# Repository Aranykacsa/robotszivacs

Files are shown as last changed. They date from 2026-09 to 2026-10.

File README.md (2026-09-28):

# Vacuum whiteboard robot — assembly prototype

The revised model uses **four drive motors**, a full-bottom sponge with an actual vacuum aperture, a gasketed adapter for a **QX-Motor 30 mm six-blade EDF / QF1611**, supported mechanical assemblies and a removable sports-car-style cover. Four TCRT5000 cartridges attach to the chassis ahead of/behind the wheels; they do not mount on the wheels.

The Blender Outliner groups parts under **Robot Components** into Chassis, Vacuum System, Drivetrain, Rear Wiper, Top Electronics, Board Sensors, Charging Contacts, Sports Car Body, Other Components and Collision Helpers. Toggle a collection's eye icon to hide/show that logical group; the individual meshes remain separate and parented to Chassis.

The hardware PDF supplies the component families. The user subsequently confirmed four motors, adhesion-only vacuum, no fixed footprint limit and a preference for printed construction. The selected EDF's duct ID/length and its mounting drawing are not supplied by the vendor, so the model's 25.5 mm bore and clamp fit are explicitly provisional. The model selects 14,000 KV for the 2S setup; check the marking on the actual motor. The vendor's 19.3 A 2S full-throttle point exceeds a 500 mAh 30C pack's nominal 15 A continuous rating.

## Open the result

- `Vacuum_Robot_Blockout.blend` — revised assembled model, component properties and studio setup.
- `robot_assembled.png`, `robot_underbody.png`, `robot_service.png` — assembled, underside and cover-off views.
- `robot_build_state.md` — flushed step-by-step component log, absolute dimensions/positions, build checks and completion status.
- `manufacturing/` — individual prototype STLs in mm, full-pad cutting template and validation report.
- `godot_vacuum_robot/project.godot` — playable whiteboard-cleaning demo built around the unchanged true-scale robot GLB.
- [Assembly and manufacturing notes](design/ASSEMBLY.md).
- [TCRT5000 mounting details and references](design/SENSOR_MOUNT.md).

The original blockout is preserved in `archive/blockout_v1/`. The original `robotszivacs.blend` is untouched.

## Generate everything

```bash
blender --background --python-exit-code 1 --python build_vacuum_robot.py -- --godot-bin /absolute/path/to/godot
```

For this machine's Flatpak Blender installation and downloaded validation binary:

```bash
flatpak run org.blender.Blender --background --python-exit-code 1 \
  --python "$PWD/build_vacuum_robot.py" -- \
  --godot-bin /home/aranykacsa/.cache/vacuum_robot_tools/godot
```

Optional arguments: `--output-dir DIR`, `--skip-render`, `--skip-godot`. Without an explicit Godot path, the script checks `GODOT_BIN`, then `godot4` and `godot` on PATH. Missing Godot is logged; an execution failure raises an exception. Rendering uses Cycles on the available device.

The script clears the current scene and replaces generated output. In Blender's Text Editor it writes beside the current `.blend`; in a fresh background session it writes beside the script. One Blender unit is one meter. STL export explicitly converts back to mm. X is right, Y is front, Z is away from the board; the board is Z=0 and the chassis base starts at Z=2 mm.

## What is checked

The script checks that every printed part is a connected manifold solid, that all robot meshes are directly parented to the one chassis object, and that object scale is applied. It checks four common shaft/hub axes, wheel and roller board contact, an open central passage and off-axis ray through EDF blade gaps, the sensors' unobstructed downward sightlines and nominal 2.5 mm optical-face height, and cover surface interference with the principal purchased-part envelopes. It exports Godot and runs headless import/runtime checks when Godot is available.

These checks do not establish actual component fit, pressure/flow performance, adhesion or production readiness. The print files are **fit prototypes**. Follow the assembly notes before fabricating final parts.

## Godot and physics metadata

The Godot project opens directly into a maximized, classroom-scale demo with Lorem Ipsum wrapped across fifteen whiteboard rows, leaving a marked lower-right docking bay. **W/S** throttle, **A/D** steer, **Home** performs a corner-parking approach and aligns the front pogo pins with two copper dock pads, and **R** resets the scene. The pad centers match the model's 32 mm pogo spacing and 104.1 mm pin reach; charging begins only when both simulated pin tips contact their pads. The robot erases text under its sponge footprint, shows cleaning progress and a one-minute battery countdown, charges while docked, and falls to the classroom floor when empty. **F11** toggles fullscreen. The robot model itself is unchanged.

Each robot mesh has `Weight` in grams, `Voltage` in volts and `Part Type`. Unknown masses/ratings are `-1`; properties distinguish generic envelopes, rated motor voltage and estimated mass. Drive motors are rated **6 V**, while the battery is **7.4 V nominal**. Do not infer electrical compatibility from the visual layout.

Helpers use `-colonly` for apertured structures and `-convcolonly` for simple envelopes. Godot removes helper visuals during import. The demo is static. Replace concave static geometry with suitable convex shapes under one `RigidBody3D` before attempting dynamic simulation; establish the finished assembly mass separately.

## References

- Local `Automata Vákuumos Táblatörlő Robot – Hardverspecifikáció.pdf`.
- [Research and downloaded complete CAD models](references/RESEARCH_AND_REDESIGN.md).
- [Vishay TCRT5000 datasheet](https://www.vishay.com/docs/83760/tcrt5000.pdf).
- [Blender glTF export API](https://docs.blender.org/api/current/bpy.ops.export_scene.html).
- [Godot import naming conventions](https://docs.godotengine.org/en/stable/tutorials/assets_pipeline/importing_3d_scenes/node_type_customization.html).

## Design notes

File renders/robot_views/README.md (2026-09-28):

# Vacuum robot render set

Fourteen PNG views rendered from `Vacuum_Robot_Blockout.blend`. The render pass changes only temporary in-memory visibility and transforms; it does not save or alter the Blender model.

## 01 Assembled Hero Hood Down

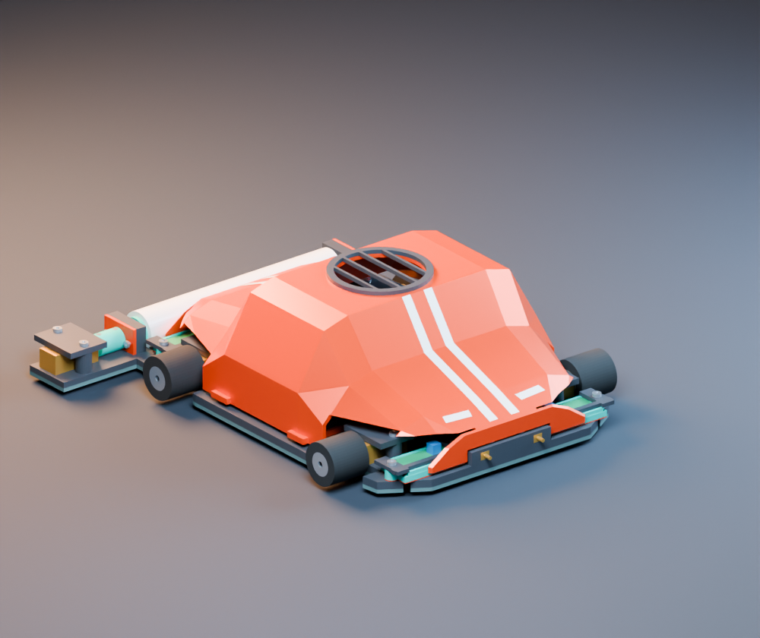
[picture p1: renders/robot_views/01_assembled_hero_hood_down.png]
01 Assembled Hero Hood Down


## 02 Front Three Quarter Hood Down

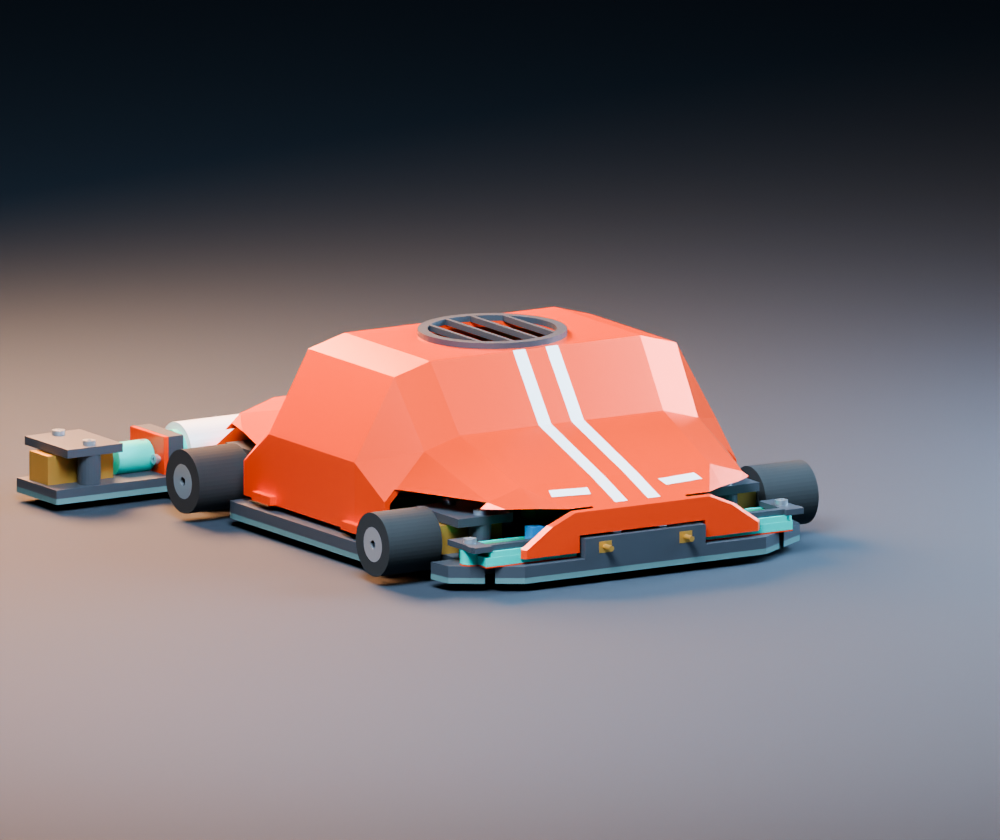
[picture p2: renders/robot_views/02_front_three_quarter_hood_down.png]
02 Front Three Quarter Hood Down


## 03 Side Profile Hood Down

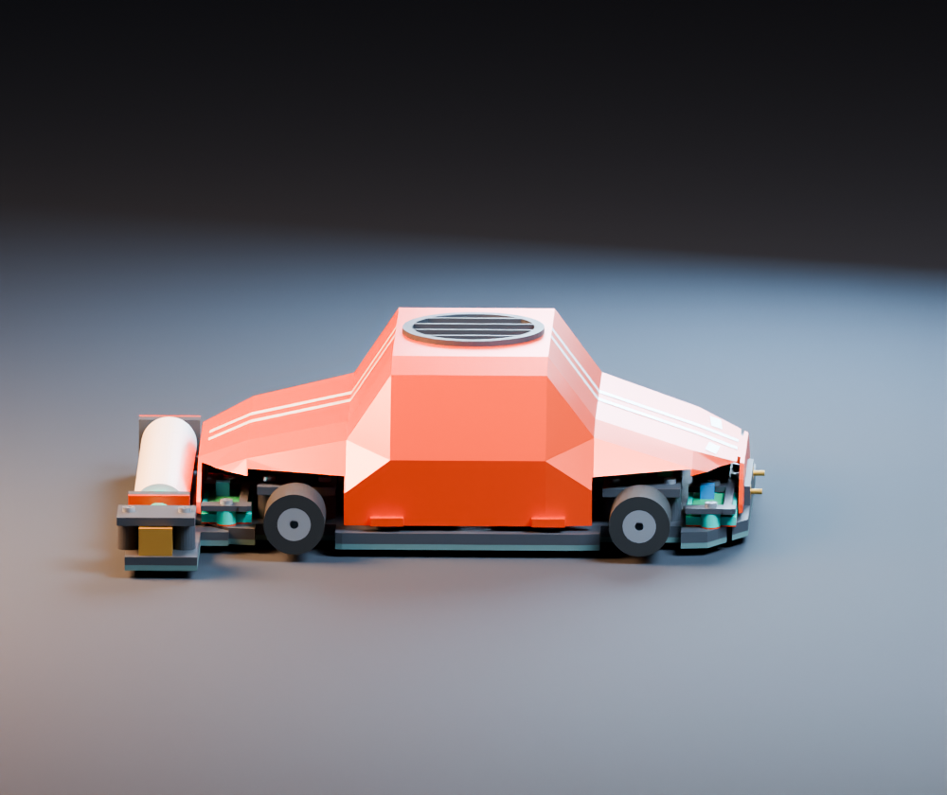
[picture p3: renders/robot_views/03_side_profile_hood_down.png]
03 Side Profile Hood Down


## 04 Rear Three Quarter Hood Down

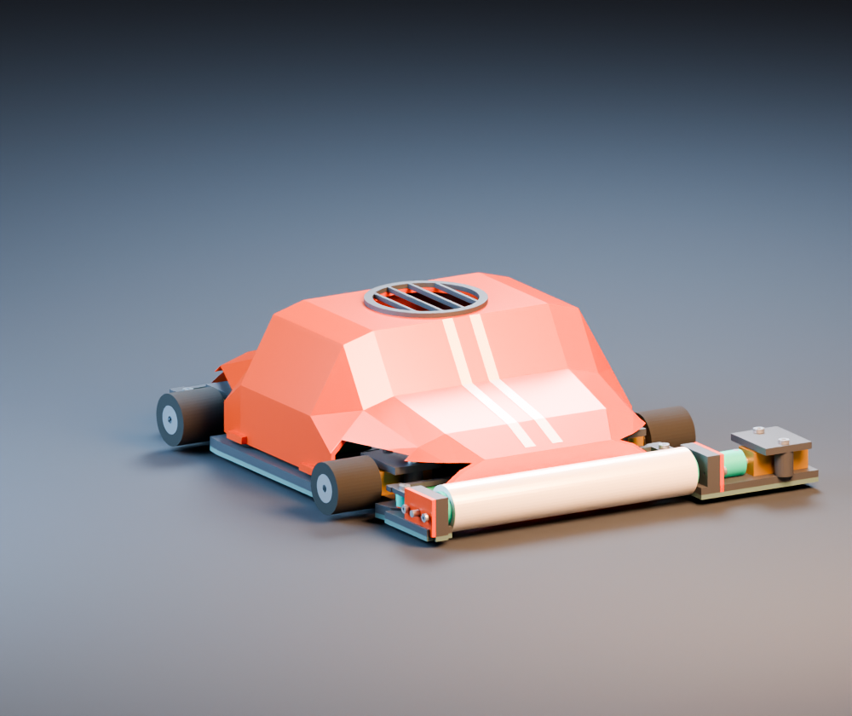
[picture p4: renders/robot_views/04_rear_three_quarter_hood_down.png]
04 Rear Three Quarter Hood Down


## 05 Top View Hood Down

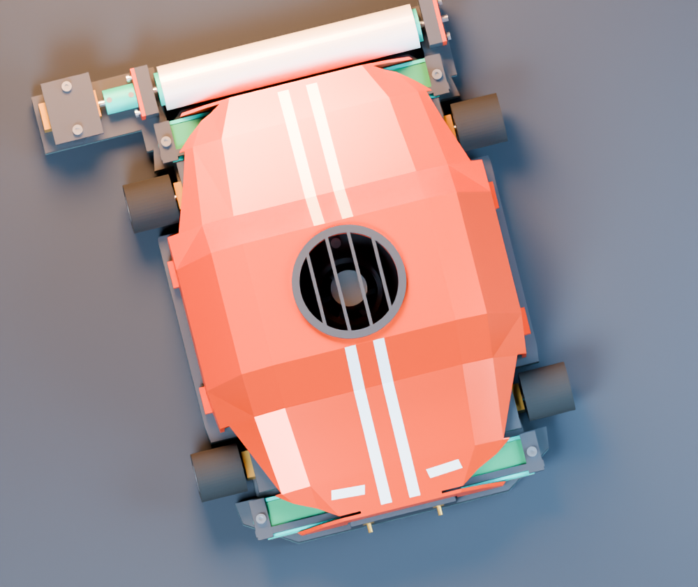
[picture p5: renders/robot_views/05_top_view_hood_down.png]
05 Top View Hood Down


## 06 Service View Hood Removed

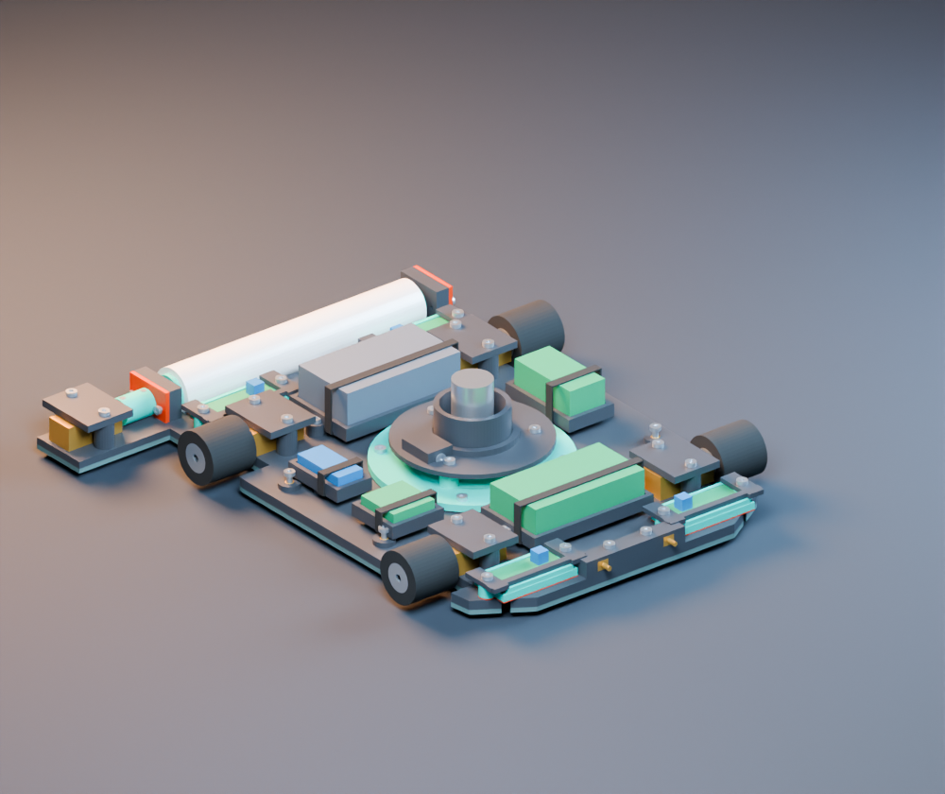
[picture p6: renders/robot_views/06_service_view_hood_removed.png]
06 Service View Hood Removed


## 07 Top View Hood Removed

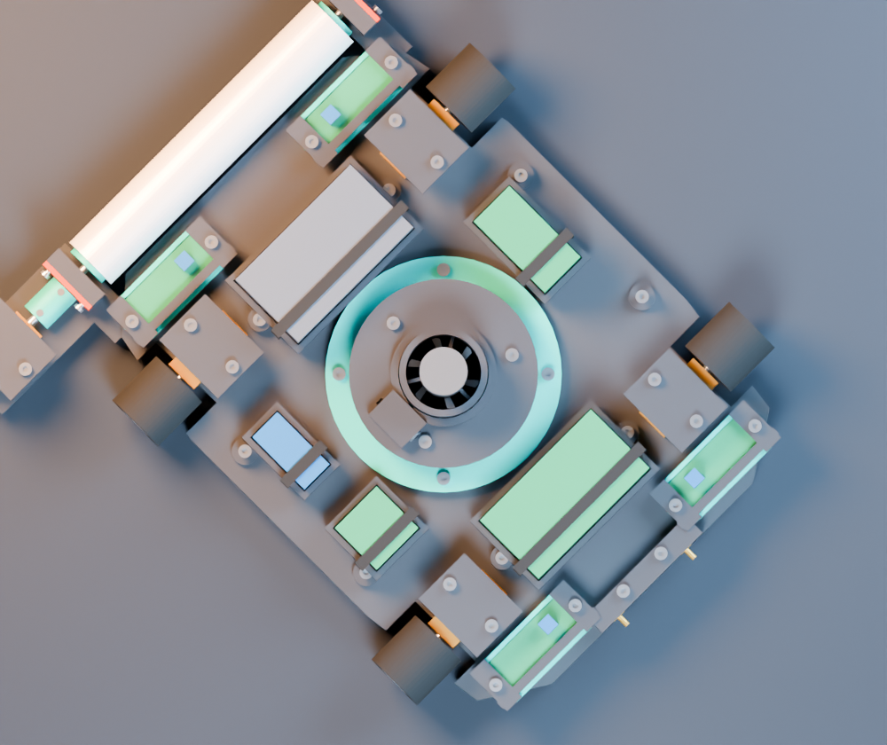
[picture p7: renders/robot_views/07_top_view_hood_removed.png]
07 Top View Hood Removed


## 08 Exploded Service Components

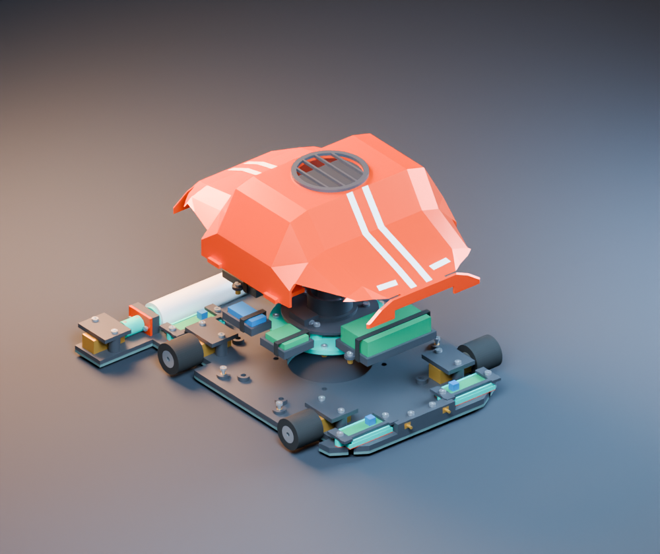
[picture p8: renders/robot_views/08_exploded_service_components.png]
08 Exploded Service Components


## 09 Full Sponge Vacuum Aperture Underside

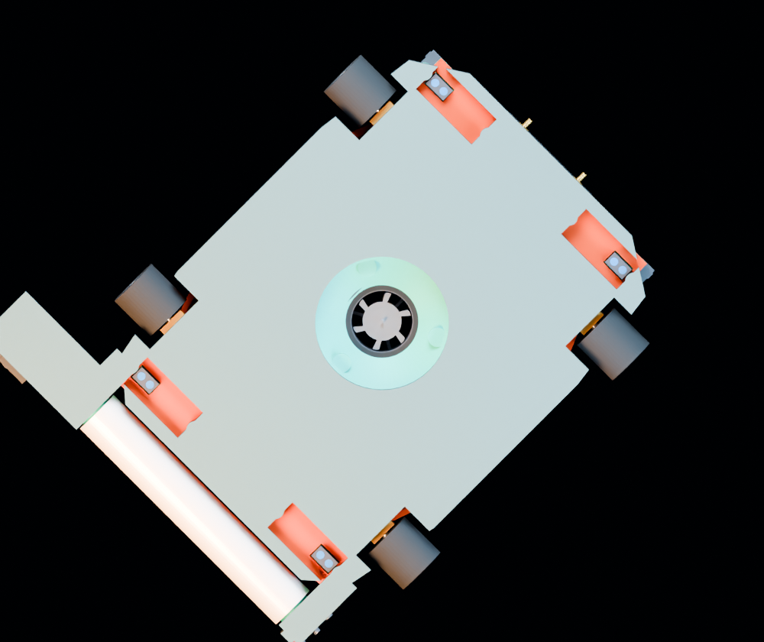
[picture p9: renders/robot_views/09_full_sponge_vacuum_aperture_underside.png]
09 Full Sponge Vacuum Aperture Underside


## 10 Tcrt5000 Sensor Mounts Underside

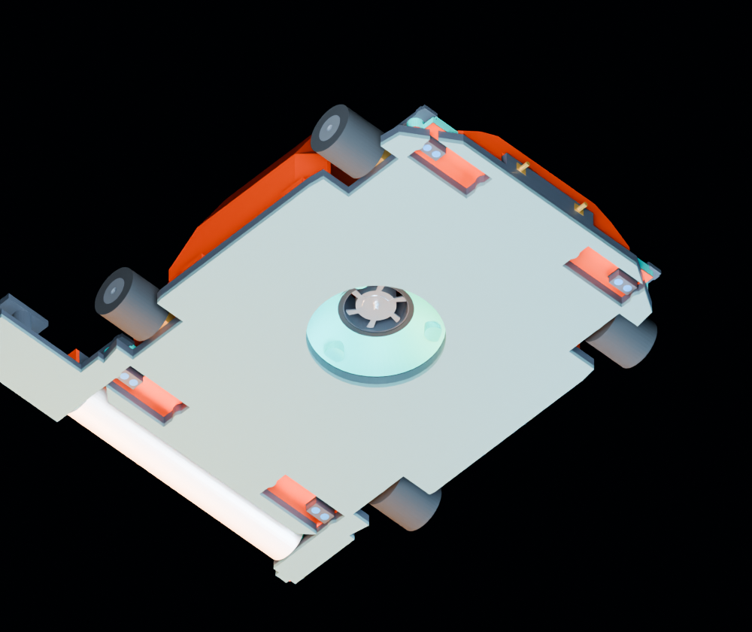
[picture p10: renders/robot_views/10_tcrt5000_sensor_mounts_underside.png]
10 Tcrt5000 Sensor Mounts Underside


## 11 Pogo Charging Contacts Front

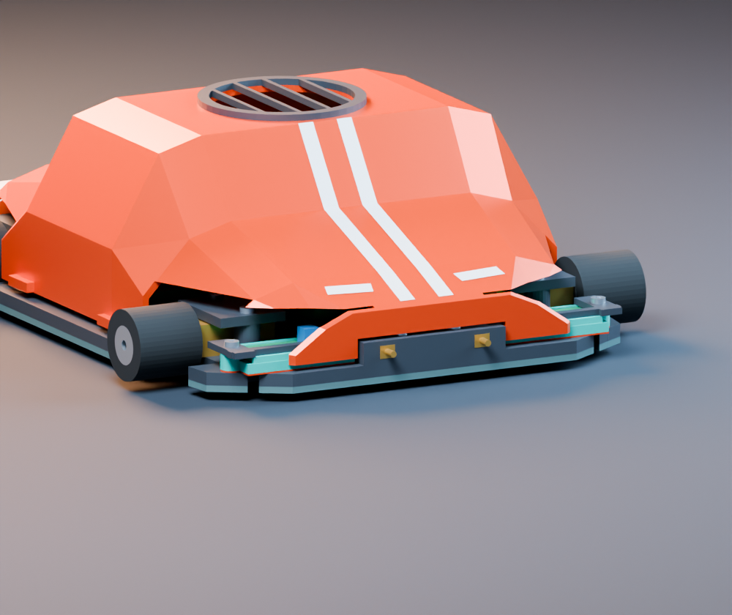
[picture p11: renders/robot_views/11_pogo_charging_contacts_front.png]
11 Pogo Charging Contacts Front


## 12 Rear Microfiber Wiper Detail

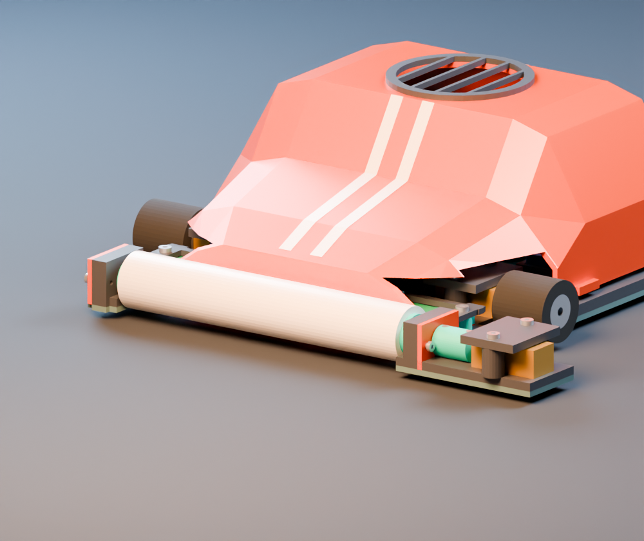
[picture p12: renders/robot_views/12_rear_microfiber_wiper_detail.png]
12 Rear Microfiber Wiper Detail


## Full Assembly Exploded View (Unlabeled)

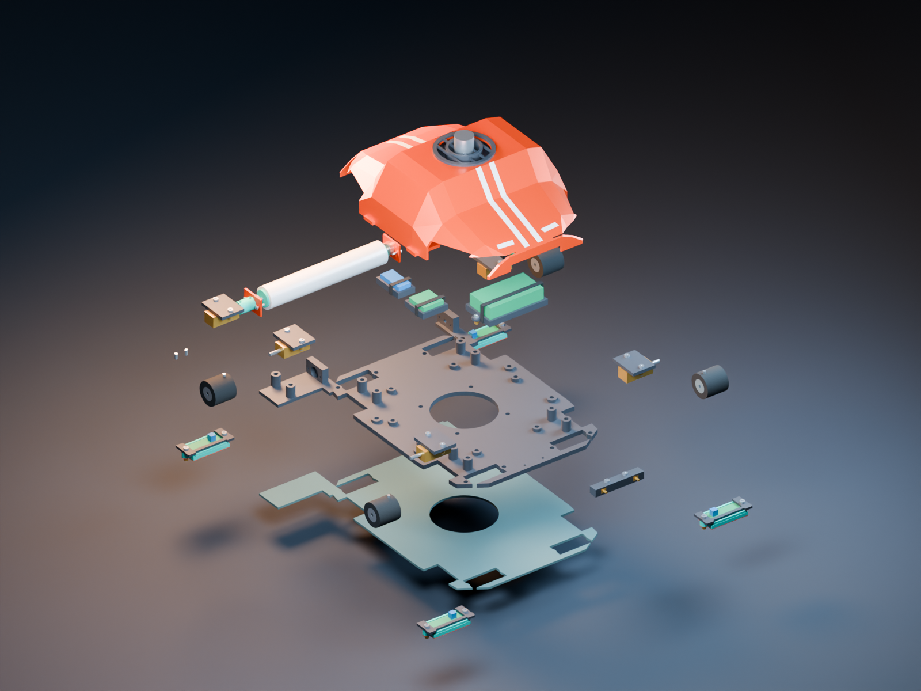
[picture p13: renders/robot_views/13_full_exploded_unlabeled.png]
Full exploded assembly without callouts


## Full Assembly Exploded View (Labeled)

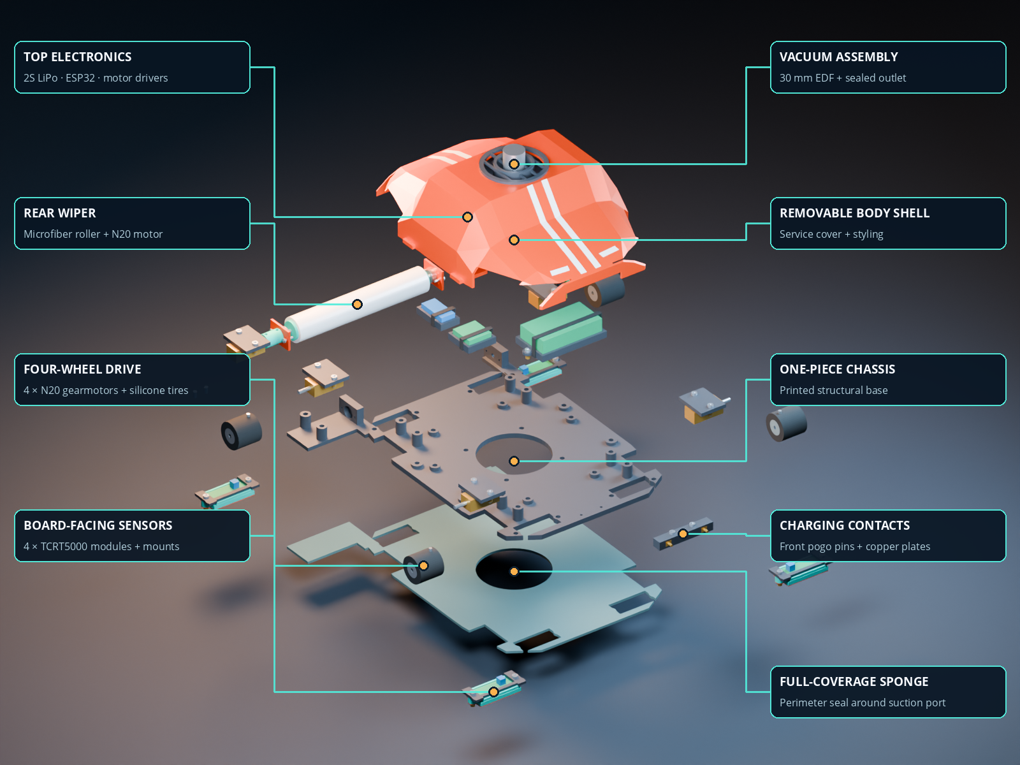
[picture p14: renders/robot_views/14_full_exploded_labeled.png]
Full exploded assembly with component callouts


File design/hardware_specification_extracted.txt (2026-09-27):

Automata Vákuumos Táblatörlő Auto
Hardverspecifikáció és Rendszerterv
1. A Rendszer Fizikai Alapelvei
A táblán (függőleges, rendkívül alacsony súrlódású felületen) való mozgás alapvető feltétele,
hogy a kerekek súrlódási ereje meghaladja a robot teljes súlyát.

 ● Képlet:

 ● Ahol a a tapadási tényező (ezt maximalizáljuk puha szilikonnal), az        pedig a
    vákuum által generált szívóerő.
 ● Mérnöki cél: A robot súlyának minimalizálása, a kerekek tapadásának maximalizálása, és

    magas statikus nyomáskülönbség (         ) létrehozása a robot alatti kamrában. Emiatt a
    vezeték nélküli töltést (MagSafe) elvetettük a magas súly és hőtermelés miatt, helyette
    100%-os hatásfokú, pehelysúlyú fizikai kontaktusos (Pogo pin) dokkolást alkalmazunk.

2. Felhasznált Alkatrészek, Paraméterek és Indoklás

 Alkatrész           Típus /            Fizikai /           Becsült Súly       Becsült Ár
                     Paraméterek        Mérnöki
                                        Indoklás

 Mikrokontroll       ESP32-S3           Könnyű, erős,       ~10 g              Meglévő (0 Ft)
 er                  (3.3V logika,      rugalmas PWM
                     beépített          kiosztással
                     Wi-Fi/BT)          rendelkezik. A
                                        Wi-Fi/BT
                                        hasznos a
                                        teszteléshez és
                                        az okosotthon
                                        integrációhoz.

 Kerekek (4          JSumo Mini         A tábla felülete    ~30 g              8 000 Ft
 db)                 Sumo szilikon      csúszós. Csak
                     kerekek            a legpuhább
                     (Shore 20A         (ragadós)
                     keménység,         szilikon biztosít
                     alu agy)           elég tapadást (

                                          ). Az

                               alumínium agy
                               garantálja,
                               hogy a vákuum
                               hatalmas
                               nyomóereje
                               alatt sem
                               deformálódik a
                               kerék.

Vákuummotor   Mikro BLDC       Axiális PC         ~60 g   8 000 Ft
              porszívó         ventilátor nem
              motor (vagy      tud elég
              30-40mm EDF,     statikus
              30 000+ RPM)
                               nyomást (
                               ) generálni. A
                               centrifugális
                               kefe nélküli
                               motor könnyű,
                               kiszívja a
                               levegőt, és
                               folyamatos
                               negatív
                               nyomást tart
                               fenn.

Meghajtó      N20 DC           A vákuum           ~20 g   5 000 Ft
motorok (2    mikromotor       miatt a robotot
db)           fém áttétellel   hatalmas erő
              (100:1 vagy      nyomja a
              300:1, 6V)       táblához, ami
                               növeli a
                               gördülési
                               ellenállást.
                               Nem
                               sebességre,
                               hanem óriási
                               nyomatékra
                               van szükség,
                               amit a fém
                               áttétel biztosít
                               minimális súly
                               mellett.

Törlőmotor     Extra N20 DC     A mikroszálas      ~10 g   2 000 Ft
               motor (vagy      henger
               könnyű 5V DC)    forgatásához.
                                Könnyű, a
                                célnak
                                megfelelő
                                nyomatékkal.

Akkumulátor    2S LiPo (7.4V,   A BLDC motor       ~40 g   5 000 Ft
               ~500 mAh,        induláskor
               30C+ kisütési    5-15A áramot
               ráta)            vesz fel. A LiPo
                                (drón akku)
                                energiasűrűsé
                                ge a
                                legmagasabb
                                (Wh/kg), és
                                képes hirtelen
                                nagy áramot
                                leadni,
                                ellentétben a
                                nehéz
                                18650-es
                                cellákkal.

Vákuum         BLHeli ESC       A kefe nélküli     ~10 g   4 000 Ft
motorvezérlő   (20A-30A,        BLDC motorok
               BEC-cel)         3 fázisú áramot
                                igényelnek,
                                amit a
                                mikrokontroller
                                nem tud
                                előállítani. Az
                                ESC PWM jelet
                                alakít át 3
                                fázisú
                                meghajtássá.

Meghajtó       TB6612FNG        Sokkal kisebb,     ~5 g    2 000 Ft
motorvezérlő   H-híd (1.2A      könnyebb és
               folyamatos /     hatékonyabb
               csatorna)        (kisebb a

                               feszültségesés
                               ), mint az
                               elavult L298N.
                               Két N20-as
                               motort tud
                               függetlenül
                               vezérelni (tank
                               irányítás).

Törlő          D4184           Az egyszerű       ~5 g    1 000 Ft
motorvezérlő   MOSFET          harmadik
               modul           motor
               (N-csatornás)   be/kikapcsolás
                               ára és
                               fordulatszámá
                               nak PWM alapú
                               szabályozására
                               a legkisebb és
                               legkönnyebb
                               megoldás.

Peremérzékel   TCRT5000 IR     Képes             ~15 g   2 000 Ft
ők (4 db)      reflexiós       érzékelni a
               modul           tábla keretét
                               (szín/távolság
                               különbség), így
                               megakadályoz
                               za, hogy a
                               robot
                               vákuumot
                               veszítve
                               lezuhanjon a
                               szélén.

Töltő          Pogo pins       100%-os           ~5 g    1 500 Ft
érintkezők     (rugós tűk) +   energiaátviteli
               réz lapkák      hatásfok, nincs
                               hőtermelés,
                               súlya szinte
                               nulla. Sokkal
                               jobb
                               alternatíva a

                                       falmászó
                                       robotoknál,
                                       mint a nehéz
                                       MagSafe
                                       tekercsek.

 Vákuum             1-2 mm             Lezárja a rést a   ~10 g               1 500 Ft
 szoknya            vékony             robot és a
                    neoprén/szilik     tábla között,
                    on lap             biztosítva a
                                       vákuumkamra
                                       szivárgásment
                                       ességét, de
                                       nem növeli
                                       drasztikusan a
                                       súrlódást.

 Törlő              Mikroszálas        A száraz           ~5 g                -
                    kendő              filcport
                    (tépőzárral a      kapilláris és
                    hengeren)          elektrosztatiku
                                       s úton gyűjti
                                       össze. Nem
                                       igényel nagy
                                       rányomási
                                       erőt,
                                       ellentétben a
                                       szivaccsal.

Összesített becsült elektronikai súly: ~225 gramm (+ a 3D nyomtatott váz)

Összesített becsült költség: ~40 000 Ft

3. Elektronikai Bekötési Terv (ESP32-S3 alapokon)
Figyelem: A rendszernek egyetlen közös Föld (GND) hálózattal kell rendelkeznie!

A. Tápellátás Logika
 1. Akkumulátor (7.4V): Közvetlenül táplálja az ESC-t és a TB6612FNG motorvezérlő VM
     (Motor Power) pinjét.
 2. ESP32-S3 táp: Az ESC szervókábelén lévő BEC (Battery Eliminator Circuit) 5V-ot biztosít.
     Ezt kell az ESP32 5V (vagy VIN) lábára kötni.
 3. Logikai táp (3.3V): Az ESP32-S3 3.3V kimenete látja el árammal a TB6612FNG VCC pinjét

    és az összes TCRT5000 szenzor VCC pinjét. (5V-ot tilos a szenzorokra kötni!)
B. Motorvezérlés (TB6612FNG - Kerekek)

 TB6612FNG Pin                  ESP32-S3 Láb                    Funkció

 PWMA                           GPIO 4                          Bal motor sebesség (PWM)

 AIN1 / AIN2                    GPIO 5 / GPIO 6                 Bal motor irány

 PWMB                           GPIO 7                          Jobb motor sebesség
                                                                (PWM)

 BIN1 / BIN2                    GPIO 15 / GPIO 16               Jobb motor irány

 STBY                           3.3V (folyamatos)               Modul engedélyezése

C. Vákuum és Törlő mechanika

 Eszköz / Pin                   ESP32-S3 Láb                    Funkció

 ESC Jel (Sárga/Fehér)          GPIO 8                          Vákuummotor vezérlése
                                                                (Szervo PWM: 1000-2000
                                                                µs)

 MOSFET PWM bemenet             GPIO 21                         Törlőmotor sebességének
                                                                szabályozása

D. Peremérzékelők (TCRT5000 Digitális kimenet)

 Szenzor Elhelyezkedés          ESP32-S3 Láb                    Funkció

 Bal Felső (DO)                 GPIO 17                         Távolság/Keret megszakítás
                                                                érzékelése

 Jobb Felső (DO)                GPIO 18                         Távolság/Keret megszakítás
                                                                érzékelése

 Bal Alsó (DO)                  GPIO 19                         Távolság/Keret megszakítás
                                                                érzékelése

 Jobb Alsó (DO)                 GPIO 20                         Távolság/Keret megszakítás

érzékelése

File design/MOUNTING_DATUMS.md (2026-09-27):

# Mounting datums (mm)

World axes: X right, Y front, Z away from the whiteboard. Board contact is Z=0.

| Interface | Datum / dimension |
|---|---|
| Chassis board-facing plane | Z=2 |
| Main chassis envelope | 152 X × 200 Y; additional rear support structure extends beyond this |
| Wheel axes | X=±75, Y=±62, Z=11 |
| Wheel envelope | Diameter 22, width 21; exact wheel SKU must be checked |
| N20 drive body envelope | 26 X × 12 Y × 10 Z at X=±50.5, Y=±62, Z=11 |
| N20 output shafts | Diameter 3, length 10; coaxial with hubs |
| Motor-clamp fasteners | X=±49, Y=wheel Y ±10; blind insert towers |
| Vacuum mouth | Diameter 56 at X=0, Y=0 |
| Adapter flange fasteners | X=±25, Y=±25 |
| Sensor PCB centers | X=±43, Y=±87 |
| Sensor optical centers | X=±53, Y=±87 |
| Nominal sensor optical-face height | Z=2.5 |
| Sensor cartridge fasteners | X=PCB center ±19, same Y; 38 mm spacing |
| Cartridge height adjustment | 0.5 mm baseline removable shim |
| Sensor cartridge to tire clearance | 5 mm in Y at the closest cartridge edge |
| Roller axis | Along X at Y=-111, Z=10 |
| Roller cleaning sleeve | Diameter 20, length 116 over a 120 mm core |
| Roller bearing envelope | 623: 3 mm bore × 10 mm OD × 4 mm width |
| Service-cover fasteners | X=±66, Y=±29 |

Coordinates come from the revised script, not from unprovided product drawings. The sensor optical package dimensions are manufacturer-based; its generic PCB placement and purchased motor/EDF fits remain prototype interfaces. QX-Motor's EDF product listing gives nominal 30 mm casing OD and QF1611 dimensions but no duct ID/length drawing; 25.5 mm ID and 16 mm length are model assumptions.

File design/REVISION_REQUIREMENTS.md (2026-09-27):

# Revised requirements

User decisions:
- Full-bottom sponge pad with a vacuum opening.
- Vacuum provides whiteboard adhesion, not dust collection.
- Prefer printed construction; use conventional hardware when it makes a better assembly.
- No fixed 140 × 120 mm envelope. Sports-car styling is desired.
- Hardware reference: `Automata Vákuumos Táblatörlő Robot – Hardverspecifikáció.pdf`.

PDF findings:
- Four Shore 20A silicone wheels with aluminum hubs, approximate combined mass 30 g.
- Two N20 drive motors, 100:1 or 300:1, rated 6 V, approximate combined mass 20 g.
- One additional N20 wiper motor, approximate mass 10 g.
- Selected QX-Motor 30 mm six-blade EDF with QF1611; duct bore/length, flange, pressure/flow curve and mounting drawing still not supplied.
- 2S 7.4 V 500 mAh 30C battery; BLHeli ESC with BEC; ESP32-S3; TB6612FNG; D4184; four TCRT5000 modules; pogo contacts.
- Original 1–2 mm sealing skirt is estimated at 10 g. Full-pad replacement mass cannot be assumed equal.
- The electronics table does not supply board outlines or mounting-hole patterns.
- PDF's estimated 225 g excludes printed chassis. Its individual listed masses total 225 g with two drive motors and a 10 g skirt.

Unresolved interface choices:
- RESOLVED: four drive motors, one per wheel, explicitly confirmed by user.
- Proceed with replaceable prototype interfaces; exact purchased-part fits remain unresolved.

Engineering interpretation:
- Keep motors rated at 6 V in properties; do not describe 7.4 V battery voltage as motor rating.
- The PDF's direct 2S motor rail requires electrical review for 6 V motors and driver current; not validated by the mechanical model.
- A full pad and an adhesion chamber must share a defined airflow path and seal. The central port should connect to the blower inlet through a gasketed adapter.
- Do not equate blower outside diameter with inlet diameter.
- Small conventional screws, steel shafts and bearings are preferable to inventing printable equivalents for rotating/load-bearing interfaces. Nonstructural panels may use printed locating features.
- Product-specific fit, pressure/flow performance, pad compression/drag and wheel traction still require physical measurements and prototype testing.

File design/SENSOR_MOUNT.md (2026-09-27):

# TCRT5000 mount

The four sensors are mounted to the chassis, at X = ±43 mm and Y = ±87 mm. Wheel axles are at X = ±75 mm and Y = ±62 mm. No sensor or bracket attaches to a wheel, hub or motor clamp.

Each assembly contains a removable printed cartridge, a 0.5 mm height shim, an edge clamp with a soft pad, and two M2.5 screws on 38 mm centers. The PCB sits on a supported ledge, while the optical package projects down through a cartridge aperture and a chassis window. The clamp bears on a PCB edge; it leaves the potentiometer accessible. This avoids inventing mounting holes on an unspecified breakout board.

The initial optical-face height is 2.5 mm above the board. Increasing shim thickness raises the sensor by the same amount; regenerate all associated sensor geometry when changing this parameter. The package is mounted pointing down (-Z), with its optical center displaced 10 mm toward the corresponding side of the chassis. The front/rear positions keep its sightline clear of the tires.

The Vishay datasheet specifies a 10.2 × 5.8 × 7 mm bare sensor package and a 2.5 mm peak operating distance. This is a starting point, not a guarantee that a particular frame, ink mark or whiteboard will produce a reliable threshold. Set the threshold on the actual board and frame after establishing the assembled contact height.

The generic PCB envelope remains 32 × 14 mm. Exact breakout variants differ in connector, trimmer and sensor placement. The cartridge is a replaceable prototype interface until the chosen module is measured.

References:
- [Vishay TCRT5000 datasheet](https://www.vishay.com/docs/83760/tcrt5000.pdf)
- [Ed Nisley's sensor mounting flange source](https://gist.github.com/ednisley/beb4491fc8db1e6960ebe8ec7dc56e7b) — reference for a supported optical-package aperture; dimensions concern the bare sensor, not the entire breakout board.
- [dehager's two-piece TCRT5000 mount and shims](https://cults3d.com/en/3d-model/tool/tcrt5000-sensor-mount-for-erc-timsav-diy-cnc-needle-cutter/makes) — reference for serviceable clamping and height adjustment. The robot's cartridge is newly modeled, not a downloaded mount with unverified fit.

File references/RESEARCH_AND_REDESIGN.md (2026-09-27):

# Manufacturing review and CAD references

Status: initial research snapshot. Revision 2 now implements the clarified architecture; see `../design/ASSEMBLY.md` and `../design/SENSOR_MOUNT.md`. The defects below describe the archived first blockout. Its manifold checks and headless smoke test validate geometry/software execution, not mechanical fit or manufacturability.

## Verified reference models

1. [Automatic Suction Powered Wall Climbing Robot](https://github.com/albindavidc/Automatic-Suction-Powered-Wall-Climbing-Robot)
   - Repository contains SolidWorks assembly `.SLDASM` and part `.SLDPRT` files, STL/3MF print parts, fan models, reports and test videos.
   - Downloaded `wall_climber_3D_Print.zip`. Closest reference for the suction adhesion architecture.
   - Assembly dependency resolution and dimensional compatibility with this robot have not been verified. GitHub reports no declared repository license; use as a reference, with reuse rights unresolved.
2. [iblowy](https://github.com/iROSLink/iblowy)
   - Confirmed `cad/iblowy.step` and `cad/iblowy.f3d` plus printable parts for a BLDC mount, fan housing halves, fan spacer, filter holder/frame, dust box, and brush motor mounts.
   - Downloaded the complete STEP file, BOM and MIT license. This is a floor vacuum, not a demonstrated wall-adhesion solution.
3. [D.A.W.E. whiteboard eraser](https://vip.bradley.edu/dawe/)
   - University project links a [public Onshape document](https://cad.onshape.com/documents/b87db0510eba9ebc45f2fa4b/w/fb9e55935966bfcd511138c9/e/75c1aa72cf430dedbd217dcf).
   - The page describes its printed frame and selected components. The Onshape link resolves, but its assembly contents/export were not inspectable through the text browser. Do not describe it as a verified downloadable complete vacuum robot.
4. [Pololu micro gearmotor and bracket CAD](https://www.pololu.com/product/1086/resources)
   - Manufacturer offers STEP models of a motor with its matching bracket.
   - Useful for actual clamping and fastener interfaces; not a silent substitution for the user's unspecified N20 motor.
5. [JSumo JS2622 wheel](https://www.jsumo.com/js2622-aluminum-silicone-wheel-pair)
   - Manufacturer specifies 26.5 mm diameter, 22 mm overall width, 3 mm bore and M4 setscrew.
   - This differs from the original 22 × 21 mm requirement. Exact wheel identity must be settled before machining/printing hub fits or fixing axle height.

Downloaded source paths and commit hashes are in `download_manifest.json`.

## Defects in the current blockout

- The chassis is solid beneath the vacuum motor. No through-port or sealed inlet-to-exhaust path exists.
- The sponge is only an 88 × 66 mm rectangular perimeter ring, not full-bottom coverage.
- The motor is a solid cylinder representing only an envelope; it contains no fan, inlet, exhaust or flange.
- Drive motors and wheels share a nominal axis but have no modeled output shafts, hub engagement, retainers or mounts.
- The roller has no shaft, bearings, coupling, supported ends or compression adjustment.
- Sensor modules float outboard; the battery and ESP32 have no supporting tray or standoffs.
- No assembly fasteners, inserts, tool access, cable passages or service access are provided.
- Collision helpers also fill the central chassis, so a new vacuum port must be reflected in collision geometry.
- The original 335 g is a specified mass total, not a weighed assembly. New mounts and hardware change the mass and center of gravity.

## Proposed revision, subject to requested construction choices

Keep a single continuous chassis solid with integral mounting bosses and wheel recesses. Add a genuine vacuum through-port matched to the selected blower inlet; do not assume inlet diameter equals its 40 mm outside diameter. Provide a sealed flange and gasket seat, an accessible exhaust and, if dust is collected, a serviceable filter path.

Replace the small skirt with a replaceable full-footprint sponge pad following the chassis perimeter and wheel reliefs. Whether the vacuum opening passes through the pad or draws through porous material is a user decision. The board-side air distribution, sponge permeability, compressed thickness and attachment layer must be considered together. A broad cleaning pad should not be assumed to behave like a perimeter vacuum seal.

Locate wheel hubs from actual output-shaft geometry and insertion length. Define motor saddles or clamp brackets with accessible fasteners, rather than a visual gap between motor and wheel. Add supported roller bearings, a motor coupling and a way to set contact pressure. Provide supported, adjustable downward sensor mounts and mechanically retained electronics/battery holders.

Before labeling the result fabrication-ready, check the chosen parts against their drawings, fastener engagement and access, printer-specific fits, minimum wall thickness, assembly order and removal of wear parts. Confirm pad drag, adhesion, wheel traction and motor loading experimentally; CAD alone cannot establish these.

## Questions recorded before revision 2

- Full pad with a vacuum opening, or continuous porous sponge?
- FDM with inserts, FDM with nuts/bolts, or another manufacturing process?
- Exact purchased parts, or documented candidate parts to review?
- Vacuum for adhesion, dust collection, or both?
- 140 × 120 mm chassis envelope, or maximum overall assembled footprint?

User subsequently specified a full pad with opening, adhesion-only vacuum, four drive motors, no fixed footprint limit and printed construction where practical. Product-specific fits remain provisional.

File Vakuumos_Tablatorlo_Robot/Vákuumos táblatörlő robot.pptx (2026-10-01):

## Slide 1

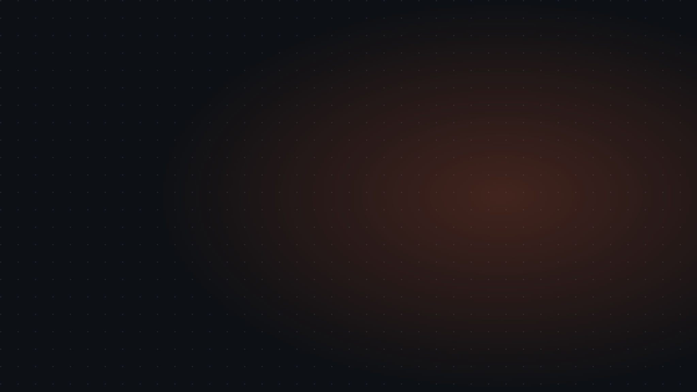
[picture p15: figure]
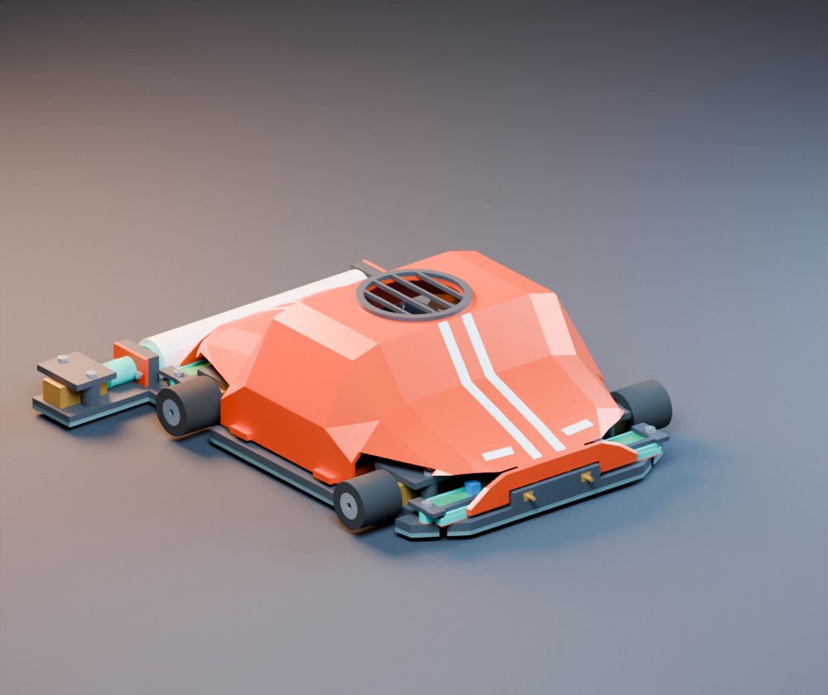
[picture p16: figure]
A robot 3D modellje

PROJEKTMUNKA · 2026

Vákuumos táblatörlő robot

116 mm törlősáv

16,8 N leszorítás

≈ 2,4 m² / töltés

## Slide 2

01 — A CÉL

A tábla automatikus letörlése

Szív

A ventilátor elszívja a levegőt a robot alól.

VÁKUUMOS TÁBLATÖRLŐ ROBOT

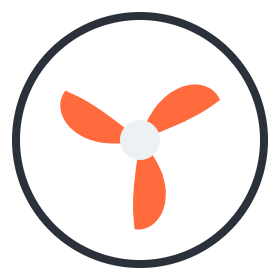
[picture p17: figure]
ventilátor

01

Tapad

A depresszió a táblához nyomja a robotot.

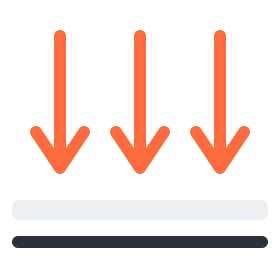
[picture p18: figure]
leszorítás

02

Halad

Négy kerék hajtja, kontrollerrel irányítva.

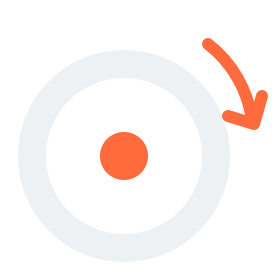
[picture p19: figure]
kerék

03

Töröl

A forgó mikroszálas henger tisztít.

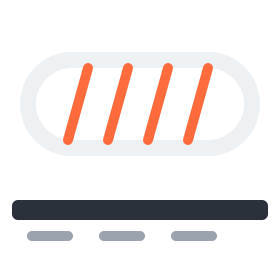
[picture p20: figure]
törlőhenger

04

02 / 09

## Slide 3

02 — FELÉPÍTÉS

Mi van benne?

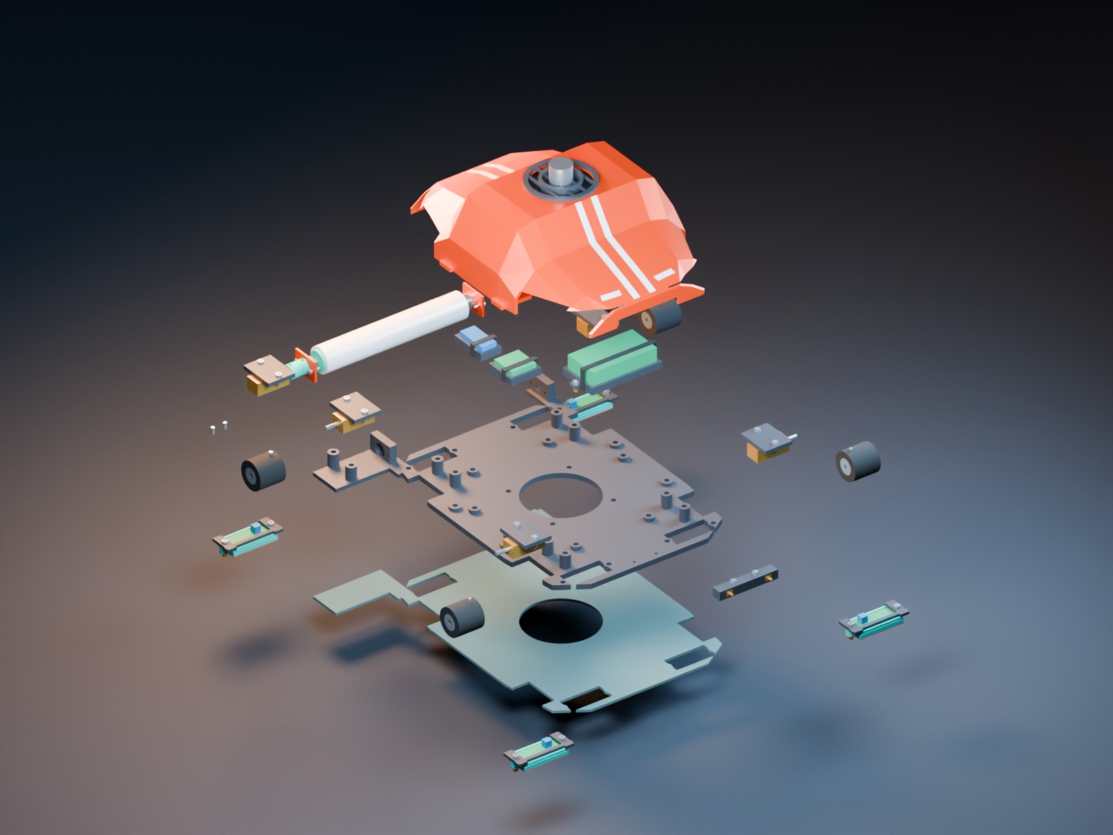
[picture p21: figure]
A robot robbantott nézete

01

Burkolat és ventilátor (EDF)

1

02

03

Forgó mikroszálas törlőhenger

Elektronika: ESP, ESC, motorvezérlő

2

3

04

Nyomtatott PETG alváz

6

05

Tömítőszivacs, 1,2 mm

4

8

06

4 szilikonkerék, 4 motor

5

7

07

4 optikai peremérzékelő

08

Töltőérintkezők

VÁKUUMOS TÁBLATÖRLŐ ROBOT

03 / 09

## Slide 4

03 — A TÖRLÉS

Forgó mikroszál, ami csúszva dörzsöl

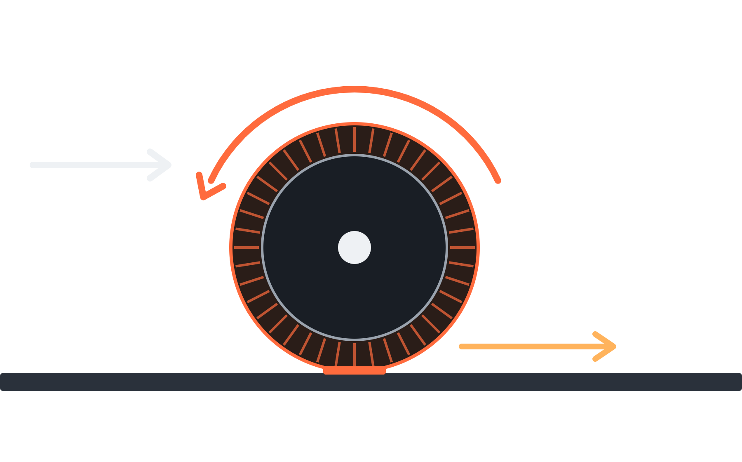
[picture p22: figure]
A törlőhenger: a haladással szemben forog, a huzat csúszik a táblán

≈ 300 1/perc, szembe

2,3 kPa

átlagos rányomás a huzaton

haladás

12 mm

mikroszál dörzsöl át minden pontot

116 mm

széles nyomot töröl egyszerre

a huzat csúszik

TÁBLA

5,2 mm

VÁKUUMOS TÁBLATÖRLŐ ROBOT

04 / 09

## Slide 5

04 — TÖRLÉSI TELJESÍTMÉNY

Ott töröl, ahová a kezelő vezeti

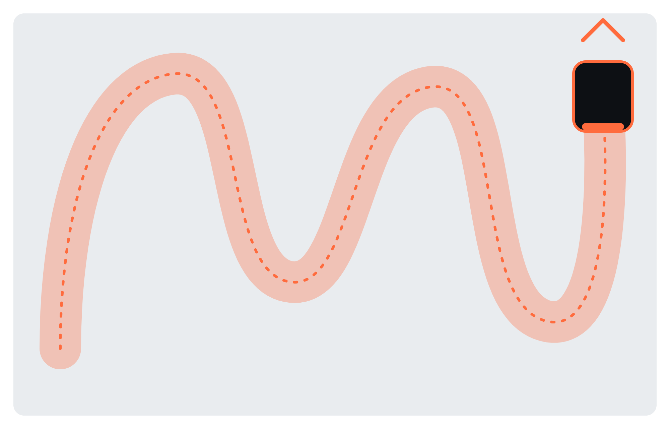
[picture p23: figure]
A kezelő által vezetett szabad törlési útvonal a táblán

≈ 2,4 m²

letörölt felület egy töltéssel

115 s

egy 180 × 120 cm-es tábla

22 mm

dörzsölés pontonként lassú fokozatban

VÁKUUMOS TÁBLATÖRLŐ ROBOT

05 / 09

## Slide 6

05 — A TAPADÁS ELVE

Vékony rés, nagy leszorító erő

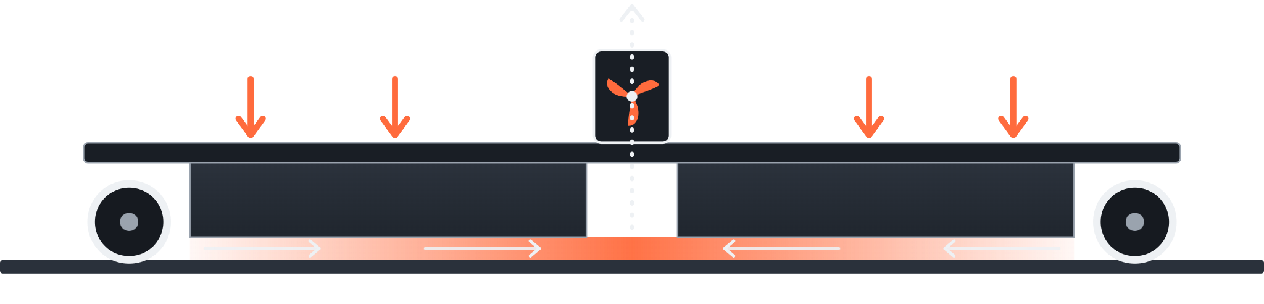
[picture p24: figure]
Keresztmetszet: a vékony résben a nyomás a robotot a táblához nyomja

↑ kifújt levegő

leszorító erő

ventilátor

TÁBLA

0,36 mm

rés a szivacs alatt

16,8 N

leszorító erő, ennek 92 %-a a kerekeken

VÁKUUMOS TÁBLATÖRLŐ ROBOT

06 / 09

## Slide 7

06 — SZÁMÍTÁS

Biztonsággal a falon

Erők a táblán felfelé haladó robotra

kerekek tapadása ↑

VÁKUUMOS TÁBLATÖRLŐ ROBOT

álló helyzet – nem csúszik le

2,12×

cél ≥ 2

felfelé haladás – nem pörög ki

F = 16,8 N

1,77×

cél ≥ 1,5

billenés – nem válik el a táblától

m·g = 5,1 N

12,8×

cél ≥ 3

07 / 09

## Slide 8


08 — ÖSSZEGZÉS

A robot számokban

116 mm

törlősáv

≈ 2,4 m²

letörölt tábla egy töltéssel

2,3 kPa

rányomás a törlőhengeren

16,8 N

leszorító erő

1,77×

mászási biztonság

512 g

tömeg

VÁKUUMOS TÁBLATÖRLŐ ROBOT

09 / 09

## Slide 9

Köszönjük a figyelmet!

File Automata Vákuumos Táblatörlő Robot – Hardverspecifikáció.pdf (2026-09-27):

# Automata Vákuumos Táblatörlő Auto

## Hardverspecifikáció és Rendszerterv

### 1. A Rendszer Fizikai Alapelvei

A táblán (függőleges, rendkívül alacsony súrlódású felületen) való mozgás alapvető feltétele, hogy a kerekek súrlódási ereje meghaladja a robot teljes súlyát.

- Képlet:
- Ahol a a tapadási tényező (ezt maximalizáljuk puha szilikonnal), az | pedig a
vákuum által generált szívóerő.
- Mérnöki cél: A robot súlyának minimalizálása, a kerekek tapadásának maximalizálása, és magas statikus nyomáskülönbség ( ) létrehozása a robot alatti kamrában. Emiatt a vezeték nélküli töltést (MagSafe) elvetettük a magas súly és hőtermelés miatt, helyette 100%-os hatásfokú, pehelysúlyú fizikai kontaktusos (Pogo pin) dokkolást alkalmazunk.

### 2. Felhasznált Alkatrészek, Paraméterek és Indoklás

Alkatrész | Típus / Paraméterek | Fizikai / Mérnöki Indoklás | Becsült Súly | Becsült Ár
Mikrokontroll er | ESP32-S3 (3.3V logika, beépített Wi-Fi/BT) | Könnyű, erős, rugalmas PWM kiosztással rendelkezik. A Wi-Fi/BT hasznos a teszteléshez és az okosotthon integrációhoz. | ~10 g | Meglévő (0 Ft)
Kerekek (4 db) | JSumo Mini Sumo szilikon kerekek (Shore 20A keménység, alu agy) | A tábla felülete csúszós. Csak a legpuhább (ragadós) szilikon biztosít elég tapadást ( ). Az | ~30 g | 8 000 Ft

alumínium agy
garantálja,
hogy a vákuum
hatalmas
nyomóereje
alatt sem
deformálódik a
kerék.

Vákuummotor Mikro BLDC porszívó motor (vagy 30-40mm EDF, 30 000+ RPM)

Axiális PC
ventilátor nem
tud elég
statikus
nyomást (
) generálni. A
centrifugális
kefe nélküli
motor könnyű,
kiszívja a
levegőt, és
folyamatos
negatív
nyomást tart
fenn.
~60 g | 8 000 Ft

Meghajtó
motorok (2
db)

N20 DC
mikromotor
fém áttétellel
(100:1 vagy
300:1, 6V)

A vákuum
miatt a robotot
hatalmas erő
nyomja a
táblához, ami
növeli a
gördülési
ellenállást.
Nem
sebességre,
hanem óriási
nyomatékra
van szükség,
amit a fém
áttétel biztosít
minimális súly
mellett.
~20 g | 5 000 Ft

Törlőmotor Extra N20 DC
motor (vagy
könnyű 5V DC)

A mikroszálas
henger
forgatásához.
Könnyű, a
célnak
megfelelő
nyomatékkal.
~10 g | 2 000 Ft
Akkumulátor | 2S LiPo (7.4V, ~500 mAh, 30C+ kisütési ráta)

A BLDC motor
induláskor
5-15A áramot
vesz fel. A LiPo
(drón akku)
energiasűrűsé
ge a
legmagasabb
(Wh/kg), és
képes hirtelen
nagy áramot
leadni,
ellentétben a
nehéz
18650-es
cellákkal.
~40 g | 5 000 Ft
Vákuum motorvezérlő | BLHeli ESC (20A-30A, BEC-cel) | A kefe nélküli BLDC motorok 3 fázisú áramot igényelnek, amit a mikrokontroller nem tud előállítani. Az ESC PWM jelet alakít át 3 fázisú meghajtássá. | ~10 g | 4 000 Ft
Meghajtó motorvezérlő | TB6612FNG H-híd (1.2A folyamatos / csatorna) | Sokkal kisebb, könnyebb és hatékonyabb (kisebb a | ~5 g | 2 000 Ft

| | feszültségesés ), mint az elavult L298N. Két N20-as motort tud függetlenül vezérelni (tank irányítás).
Törlő motorvezérlő | D4184 MOSFET modul (N-csatornás) | Az egyszerű harmadik motor be/kikapcsolás ára és fordulatszámá nak PWM alapú szabályozására a legkisebb és legkönnyebb megoldás. | ~5 g | 1 000 Ft
Peremérzékel ők (4 db) | TCRT5000 IR reflexiós modul | Képes érzékelni a tábla keretét (szín/távolság különbség), így megakadályoz za, hogy a robot vákuumot veszítve lezuhanjon a szélén. | ~15 g | 2 000 Ft
Töltő érintkezők | Pogo pins (rugós tűk) + réz lapkák | 100%-os energiaátviteli hatásfok, nincs hőtermelés, súlya szinte nulla. Sokkal jobb alternatíva a | ~5 g | 1 500 Ft

| | falmászó robotoknál, mint a nehéz MagSafe tekercsek.
Vákuum szoknya | 1-2 mm vékony neoprén/szilik on lap | Lezárja a rést a robot és a tábla között, biztosítva a vákuumkamra szivárgásment ességét, de nem növeli drasztikusan a súrlódást. | ~10 g | 1 500 Ft
Törlő | Mikroszálas kendő (tépőzárral a hengeren) | A száraz filcport kapilláris és elektrosztatiku s úton gyűjti össze. Nem igényel nagy rányomási erőt, ellentétben a szivaccsal. | ~5 g | -

Összesített becsült elektronikai súly: ~225 gramm (+ a 3D nyomtatott váz) Összesített becsült költség: ~40 000 Ft

### 3. Elektronikai Bekötési Terv (ESP32-S3 alapokon)

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

érzékelése

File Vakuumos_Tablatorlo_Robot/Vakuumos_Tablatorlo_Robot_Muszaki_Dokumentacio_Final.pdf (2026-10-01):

# Vákuumos táblatörlő robot


## 1 A robot röviden

A projekt célja a fehértábla letörlése. A robot a táblán mozog, és a hátsó, forgó mikroszálas hengerrel letörli a filcnyomot. Ehhez két feltételnek kell teljesülnie: a hengernek egyenletesen, elegendő nyomással kell a táblához érnie és dörzsölnie, a robotnak pedig a táblán kell maradnia és mozognia.

A falon a ventilátor tartja: az alváz alól levegőt szív el, és az így kialakuló depresszió (Δp) a robotot a táblához nyomja. A teljes aljat fedő szivacs vékony (kb. 0,36 mm-es) réssel tömít, így a depresszió az egész szivacs alatt hat, a leszorító erőt pedig a négy szilikonkerék fogja fel.

A robotot a kezelő vezeték nélküli kontrollerrel irányítja, és oda vezeti, ahol törölni kell. A biztonsági feladatokat (peremvédelem, kapcsolatvesztés, álló helyzetben tartás) a robotban lévő ESP önállóan látja el. Töltés a táblára szerelt dokkolóban, rugós érintkezőkön keresztül történik.

### 1.1 Fő műszaki adatok

Jellemző | Érték

Törlés

Törlőeszköz | forgó mikroszálas henger, Ø20 × 116 mm

Tapadás

Ventilátor | 30 mm-es EDF
Depresszió | 2,0 kPa

Leszorító erő | 16,8 N
Tömítés | 1,2 mm-es szivacs, ≈ 0,36 mm-es réssel

Robot

Befoglaló méret | 201 × 229 × 66 mm

Legnagyobb sebesség

Energia és vezérlés

Akkumulátor | 2S LiPo, 7,4 V, 500 mAh
Áramfelvétel | ≈ 11,4 A
Üzemidő | ≈ 2 perc (126 s)
Irányítás | vezeték nélküli kontroller
Érzékelők | 4 peremérzékelő, gyorsulásmérő
Töltés | dokkoló, 2 érintkező

## 2 Felépítés

Az alváz egy darabból nyomtatott PETG lemez, erre csavarozódik minden alkatrész. Középen a ventilátor ül: az alvázból elszívott levegőt a burkolat rácsán fújja ki. A négy motor közvetlenül hajtja a kerekeket; a bal és a jobb oldali pár együtt kap jelet (tank-kormányzás). A hátsó, Ø20 × 116 mm-es mikroszálas törlőhengert külön motor forgatja; a huzat tépőzárral rögzül, levehető és mosható. A sarkokban négy optikai érzékelő figyeli a tábla szélét, elöl két töltőtüske csatlakozik a dokkolóhoz. Az alváz alján a teljes aljat fedő, 1,2 mm vastag zártcellás szivacs ül (a kerekeknél és az érzékelőknél kivágással). A burkolat levehető.


2. ábra – Belső elrendezés (burkolat nélkül) és a táblára néző oldal fő méretei [mm]

### 2.1 Alkatrészek és tömeg

Tétel | Típus | Tömeg [g]
Mikrovezérlő | ESP32-S3 | 10
Kerekek (4 db) | szilikon Shore 20A, Ø22 × 21 mm, alu agy | 30
Törlőmotor | N20 | 10
Törlőhenger-huzat | mikroszálas, 2,5 mm, tépőzáras | 5,0
Akkumulátor | 2S LiPo 7,4 V, 500 mAh, 30C | 40
ESC | BLHeli 20–30 A, 5 V BEC-kimenettel | 10
Motorvezérlő | TB6612FNG H-híd | 5,0
Törlőmotor-kapcsoló | D4184 MOSFET modul | 5,0
Peremérzékelők (4 db) TCRT5000 optikai modul | 15
Gyorsulásmérő | MPU-6050 modul | 2,0
Töltőérintkezők | pogo tüskék + réz lapkák | 5,0
Tömítőszivacs | zártcellás hab, 1,2 mm, vékony ragasztóval | 4,5
Nyomtatott elemek | 32 db PETG alkatrész | 251
Egyéb | kötőelemek, tengely, csapágyak, kábelek | 57

Robot összesen | | 512
Kontroller | vezeték nélküli játékvezérlő | –

## 3 A törlés

### 3.1 A törlőhenger

A törlést a robot hátulján lévő henger végzi: a Ø15 mm-es nyomtatott magon 2,5 mm vastag mikroszálas huzat ül (Ø20 × 116 mm). A mikroszál a száraz filcport kapilláris és elektrosztatikus úton köti meg, ezért nem kell nagy erővel a táblához nyomni. A hengert saját motor forgatja (kb. 300 1/perc fordulattal számolva), a haladással ellentétes irányban, mint egy kefét: így a huzat nem gördül, hanem csúszik és dörzsöl a táblán. A forgatáshoz μ ·F ·R = 0,4 · 1,39 · 0,010 = 0,0056 N·m nyomaték kell, ami egy N20

h h
motornak kis terhelés.


3. ábra – A törlőhenger oldalnézetben: a huzat a haladással szemben forog és csúszik a táblán

### 3.2 Rányomás

A henger tengelye a kerekekével azonos magasságban van, a huzat nyugalomban éppen érinti a táblát. Üzem közben a leszorító erő a kerekeket kb. 0,34 mm-rel összenyomja (4.5), ennyivel nyomódik be a huzat is. A huzatot vékony rugalmas rétegként kezelve (L = 116 mm hossz, R = 10 mm sugár, t = 2,5 mm vastagság, E ≈ 25 kPa becsült rugalmassági modulus):

c = (4/3)·E·L·√(2R) / t = (4/3) · 0,025 · 116 · √20 / 2,5 = 6,92 N/mm¹,5

h
F = c ·δ

1,5 = 6,92 · 0,343¹,5 = 1,39 N h h
b = 2·√(2·R·δ) = 2·√(2 · 10 · 0,343) = 5,24 mm é
p = F / (L·b ) = 1,39 / (116 · 5,24) = 2,3 kPa h | é
A henger tehát 5,2 mm széles sávon, átlagosan 2,3 kPa nyomással ér a táblához. A benyomódás szórása (0,2–0,5 mm) mellett a henger ereje 0,6–2,4 N között marad, a huzat tehát mindig a táblán van.

### 3.3 Dörzsölés

Mivel a henger a haladással szemben forog, a huzat a táblához képest a két sebesség összegével csúszik. Egy pont annyi ideig van a henger alatt, amíg a robot megteszi az érintkezési szélességet; ezalatt a huzat ekkora hosszon dörzsöli át:

v = n·π·D = 300/60 · π · 0,020 = 0,314 m/s
h
s = (v + v )·b / v = (0,25 + 0,314) · 5,24 / 0,25 = 12 mm h é
Normál sebességnél (0,25 m/s) minden pontot kb. 12 mm huzat dörzsöl át, az érintkezési szélesség 2,3-szerese; lassú fokozatban (0,10 m/s) 22 mm, a 4,1-szerese. Makacsabb foltokra a lassú fokozat vagy egy második áthaladás való. Hátramenetben a henger a gördülés irányába forog, és csak kb. 1 mm-t dörzsöl, ezért a robot előremenetben töröl hatékonyan.

### 3.4 Törlési teljesítmény

A kezelő a kontrollerrel szabadon vezeti a robotot oda, ahol törölni kell. Egy teljes tábla letörlésekor a 116 mm-es nyomokat kb. 16 mm-es átfedéssel érdemes egymás mellé tenni, így menetenként 100 mm tisztul.
A fordulók miatt a menetidő kb. 75 %-ával számolva:

q = b·v·η = 0,100 m · 0,25 m/s · 0,75 = 0,019 m²/s
A = q·t = 0,019 m²/s · 126 s ≈ 2,4 m²
Fokozat | Sebesség | Dörzsölés pontonként | Teljesítmény | Egy töltéssel
Normál | 0,25 m/s | 12 mm | 0,019 m²/s | ≈ 2,4 m²
Lassú | 0,10 m/s | 22 mm | 0,0075 m²/s | ≈ 0,9 m²

Egy 180 × 120 cm-es tábla (2,16 m²) normál fokozatban kb. 115 s alatt, egy töltéssel letörölhető. A letörölt port a huzat köti meg; a huzatot időnként le kell venni és ki kell mosni.

## 4 Méretezés – miért marad a falon?

### 4.1 Bemenő adatok

Jel | Jelentés | Érték
m·g | a robot súlya | 0,52 kg · 9,81 m/s² = 5,10 N

μ
k
kerék–tábla súrlódási tényező (becslés) | 0,7

μ
h
törlőhenger–tábla súrlódási tényező (becslés) | 0,4

c
g
gördülési ellenállás tényezője (becslés) | 0,03
F h | a törlőhenger szorítóereje (3.2) | | 1,39 N
β | a leszorító erő kerekekre jutó hányada (4.5) | 0,92
Δp | depresszió a szívónyílásban | | 2,0 kPa

h
TK
a tömegközéppont távolsága a táblától | 16 mm
a | a szívónyílás közepének távolsága az alsó tengelytől | 62 mm

### 4.2 A falon maradás feltételei

A depresszió F erővel nyomja a robotot a táblához; ennek β része a kerekekre, a többi a törlőhengerre

N
jut. A robot akkor marad biztosan a falon, ha álló helyzetben nem csúszik le, felfelé haladva nem pörögnek meg a kerekei, és nem billen el a tábláról:
csúszás: | S = μ ·β·F / (m·g) ≥ 2 cs | k
N
mászás: | S = μ ·β·F / [ m·g + μ ·F + c ·β·F ] ≥ 1,5 m k N h h g N
billenés: | S = F ·a / (m·g·h ) ≥ 3
b | N | TK
Mászáskor a kerekek tapadásának a súlyon kívül a törlőhenger súrlódását és a gördülési ellenállást is le kell győznie. Billenésnél a súly h karon próbálja elfordítani a robotot az alsó kerékpár körül, a leszorító

TK
erő a karon tartja vissza.


4. ábra – A táblán felfelé haladó robotra ható erők

### 4.3 Szívóerő

A ventilátor a gyártó szerint T = 2,11 N (215 g) tolóerőt ad. A kifújási keresztmetszet a 25,5 mm-es csatorna és a 16,3 mm-es motor közti gyűrű, A = 302 mm². Mivel T = ρ·A·v², a ventilátor legnagyobb j j
depressziója:

Δp ≈ ½·ρ·v² = T / (2·A ) = 2,11 / (2 · 302·10⁻⁶
) ≈ 3,5 kPa max j
A ventilátor a Ø56 mm-es nyíláson át szív, a levegő a szivacs alatti résen át sugárirányban áramlik befelé és közben felgyorsul. A nyomás a nyílásnál a teljes Δp, a szivacs szélén nulla, így a depresszió a szivacs alatt is húzza a robotot. A nyomáseloszlást a szivacssablon tényleges körvonalán, a résbeli súrlódással és a levegő gyorsulásával számolva a hatásos felület és a leszorító erő:

A ≈ 8400 mm² (ebből a nyílás 2463 mm²) F = Δp·A =
2000 Pa · 0,0084 m² = 16,8 N

N
h = 0,36 mm-es résnél (4.5) a 2,0 kPa-hoz 76 %-os ventilátorfordulat kell, a szivárgás kb. 1,8 l/s. A rés méretének hatása:
Rés h [mm] | Szivárgás [l/s] | Δp normál (76 %) [kPa] | Δp erős (84 %) [kPa]
0,2 | 0,4 | 2,02 | 2,47
0,3 | 1,2 | 2,01 | 2,45
0,4 | 2,3 | 1,99 | 2,42
0,5 | 3,5 | 1,94 | 2,36
0,6 | 4,7 | 1,88 | 2,28

A gyártási szórás a rést kb. 0,1 és 0,6 mm közé teszi. A legnagyobb résnél normál fokozatban is 1,7-szeres a csúszás elleni biztonság, erős fokozatban ismét 2 feletti.

### 4.4 Biztonsági tényezők S = 0,7 · 15,5 / 5,10 = 2,12 ≥ 2

✓ cs
F = 5,10 + 0,4·1,39 + 0,03·15,5 = 6,12 N szüks F = 0,7·15,5 = 10,82 N tap
S = 10,82 / 6,12 = 1,77 ≥ 1,5 ✓ m
S = 16,8 · 0,062 / (5,10 · 0,016) = 12,8 ≥ 3 ✓ b
Itt β·F = 15,5 N a kerekekre jutó erő (4.5). Visszaszámolva álló helyzetben 1,89 kPa, mászáshoz 1,65 kPa
N depresszió elég; a 2,0 kPa ennél 6 %-kal, illetve 21 %-kal több. Ha a depresszió csak a Ø56 mm-es nyílás alatt hatna, a leszorító erő 4,9 N, a csúszás elleni biztonság pedig 0,62 lenne; a vékony rés teszi lehetővé, hogy a nyomás a szivacs alatt is hasson.

### 4.5 Kerekek és tömítőszivacs

A táblához a kerekeken kívül csak a törlőhenger ér hozzá. Az alsó szivacs szándékosan nem: 250 cm²-en felfekve olyan merev lenne (kb. 500 N/mm), hogy a kerekek benyomódásánál gyakorlatilag a teljes leszorító erőt ő venné fel, és a robot nem tudna elindulni. A kerekek és a henger ugyanannyit nyomódnak be (c = 19,2 N/mm¹,5 a Shore 20A szilikonkerék becsült merevsége, c a hengeré, 3.2): k
h
δ = ( F / (4·c + c ) )²/3 = ( 16,8 / (4·19,2 + 6,9) )²/3 = 0,34 mm
N | k | h
β = (F − F ) / F = (16,8 − 1,39) / 16,8 = 0,92
N | h | N
A rés a kerekek és a szivacs méretéből adódik: a modell szerint az alváz alja 2,0 mm-rel van a kerekek talppontja fölött:
h = 2,0 − t | − t | − δ = 2,0 − 1,2 − 0,1 − 0,34 = 0,36 mm szivacs | ragasztó

### 4.6 Hajtás és tartás

F = F | / 4 = 6,12 / 4 = 1,53 N kerék | szüks
M = F | | ·r = 1,53 · 0,011 = 0,017 N·m ≈ 0,17 kg·cm
kerék
Egy 300 1/perc-es N20 motor elakadási nyomatéka jellemzően ennek többszöröse. A súly a felső kerekeket kissé tehermentesíti (0,66 N-nal), de ezek tapadása (2,47 N) így is nagyobb a szükséges 1,53 N-nál. A legnagyobb sebesség v = n·π·D = 300/60 · π · 0,022 ≈ 0,35 m/s, mászás közben ennél valamivel kisebb. Helyben fordulni is tud: a hajtó nyomaték (0,81 N·m) kb. 11 %-kal nagyobb, mint a kerekek oldalirányú csúszásából és a henger súrlódásából adódó ellenállás, ezért a vezérlés a fordulást lassúra korlátozza.

A motorok áttétele nem önzáró, ezért álló helyzetben a kerekeket tartani kell. A vezérlő a gyorsulásmérőből tudja, merre van lefelé, és a motorokra a súly haladásirányú összetevőjének megfelelő nyomatékot adja (legfeljebb kerekenként 1,28 N, azaz 0,014 N·m). A kerekek tapadása (μ ·β·F /4 = 2,7 N
k N kerekenként)
ennél jóval nagyobb, így a kerekek nem csúsznak meg.

### 4.7 Energia és üzemidő

A ventilátor teljesítménye a fordulatszám köbével arányos (gyártói adat teljes fordulaton: 142,8 W); zárt térből szívva 20 % ráhagyással:

P = 1,2 · 142,8 · 0,761³ = 75,5 W EDF

Fogyasztó | Teljesítmény [W] | Áram 7,4 V-on [A]
Ventilátor | 75,5 | 10,2
4 hajtómotor | 6,7 | 0,90
Törlőmotor | 1,0 | 0,14
Vezérlés, rádió, érzékelők | 1,5 | 0,20
Összesen | 84,7 | 11,4

Az üzemidő az akku energiájából, 80 %-os kihasználással (DoD = 0,8):

t = U·C·DoD / P = 7,4 V · 0,5 Ah · 0,8 / 84,7 W = 0,035 h ≈ 126 s
Az akku legfeljebb 15 A-t ad le (500 mAh · 30C), ezért a program a ventilátor fordulatát 84 %-ban korlátozza (erős fokozat). A kb. 2 perc a 3.4 szerint kb. 2,4 m² tábla letörlésére elég, utána a robot a dokkolóban tölt.

### 4.8 Megállás a tábla szélénél

Az első érzékelők 25 mm-rel a kerekek előtt vannak. 10 ms érzékelési késéssel és 50 ms fékezési idővel a fékút:

s = v·t + v·t / 2 = 0,35·0,01 + 0,35·0,05 / 2 = 12,3 mm < 25 mm ✓ k f
Lefelé haladva a fékezéshez a súlyt is le kell győzni: m·a + m·g = 0,52 · 7,0 + 5,10 = 8,7 N (a = v/t ), ami f kisebb a 10,8 N tapadóerőnél. A kezelő reakcióidejével (kb. 0,5 s) a robot kb. 17 cm-t tenne meg, ezért a peremvédelem a robotban fut, és felülírja a kontroller parancsát.

## 5 Elektronika és irányítás

Az akku közvetlenül táplálja az ESC-t, a motorvezérlőt és a törlőmotort. Az ESP az ESC 5 V-os kimenetéről kap tápot, az érzékelők az ESP 3,3 V-os kimenetéről. Minden egység közös földön van. A robotot a kezelő vezeték nélküli kontrollerrel irányítja, a parancsokat a robotban lévő ESP fogadja.


5. ábra – Blokkvázlat

### 5.1 Bekötés

Funkció | ESP láb | Jel
Ventilátor (ESC) | GPIO8 | szervojel 1000–2000 µs, legfeljebb 84 %
Bal motorpár: sebesség / irány | GPIO4 / GPIO5, 6 | PWM 20 kHz, legfeljebb 70 % (6 V-os motorok 8,4 V-ról)
Jobb motorpár: sebesség / irány | GPIO7 / GPIO15, 16 | PWM 20 kHz, legfeljebb 70 %
Törlőmotor (MOSFET) | GPIO21 | PWM, a motoron védődióda
Peremérzékelők | GPIO17, 18, 9, 10 | digitális bemenet
Gyorsulásmérő | GPIO11, 12 | I²C (SDA, SCL)
Akkufeszültség | GPIO1 | feszültségosztó 100 kΩ / 33 kΩ (8,4 V → 2,1 V)

### 5.2 Biztonsági logika

A legfontosabb szabály: a táblán lévő robotnál a ventilátor soha nem áll le magától. Hiba esetén mindig a hajtás áll meg, a ventilátor tovább tartja a robotot.

Esemény | A robot reakciója
Megszakad a kapcsolat (200 ms) | megáll és tartó üzemmódba vált (addig legfeljebb 7 cm-t halad), a henger leáll
Peremérzékelő jelez | a perem felé mozgás tiltva, csak eltávolodás engedett
Az akku lemerülőben (6,8 V alatt) | lassú üzemmód; a ventilátor nem áll le
Ventilátor leállítása | csak szándékos, hosszan nyomott gombbal, kézben tartott vagy dokkolt robotnál
Indítás | a hajtás csak a ventilátor 2–3 s-os felpörgése után indulhat

## 6 Összegzés

A projekt célja a fehértábla letörlése. A robotot a kezelő kontrollerrel vezeti a táblán, a hátsó, a haladással szemben forgó mikroszálas henger pedig letörli a filcport. A henger 116 mm széles sávon, átlagosan 2,3 kPa nyomással ér a táblához, minden pontot kb. 12 mm huzattal dörzsöl át, és egy töltéssel kb. 2,4 m², azaz egy 180 × 120 cm-es tábla letörlésére képes.

A táblán a vákuum tartja: a 30 mm-es ventilátor a Ø56 mm-es nyíláson át szív, a teljes aljat fedő szivacs kb. 0,36 mm-es réssel tömít, így a 2,0 kPa depresszió 16,8 N-nal nyomja a 0,52 kg-os robotot a táblához. Álló helyzetben 2,1-szeres, felfelé haladva 1,8-szeres biztonsággal tapad, billenés ellen 13-szoros a tartalék. A robot a meglévő 3D modell szerint épül; az egyetlen megkötés az 1,2 mm vastag tömítőszivacs.

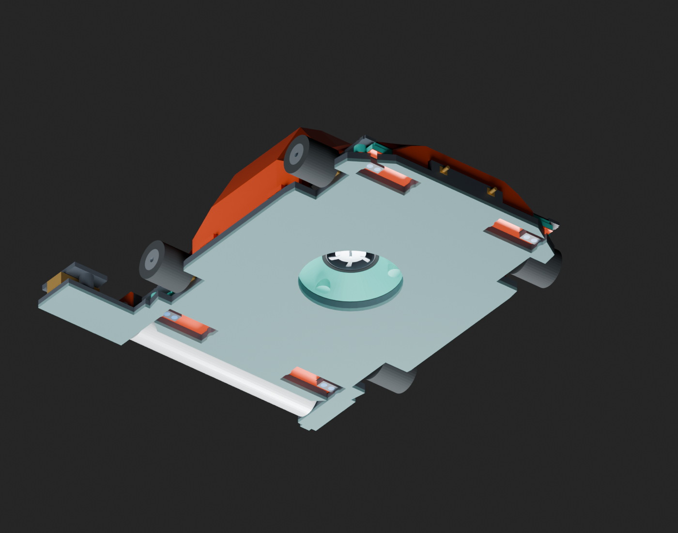
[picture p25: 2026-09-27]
robot_underbody.png

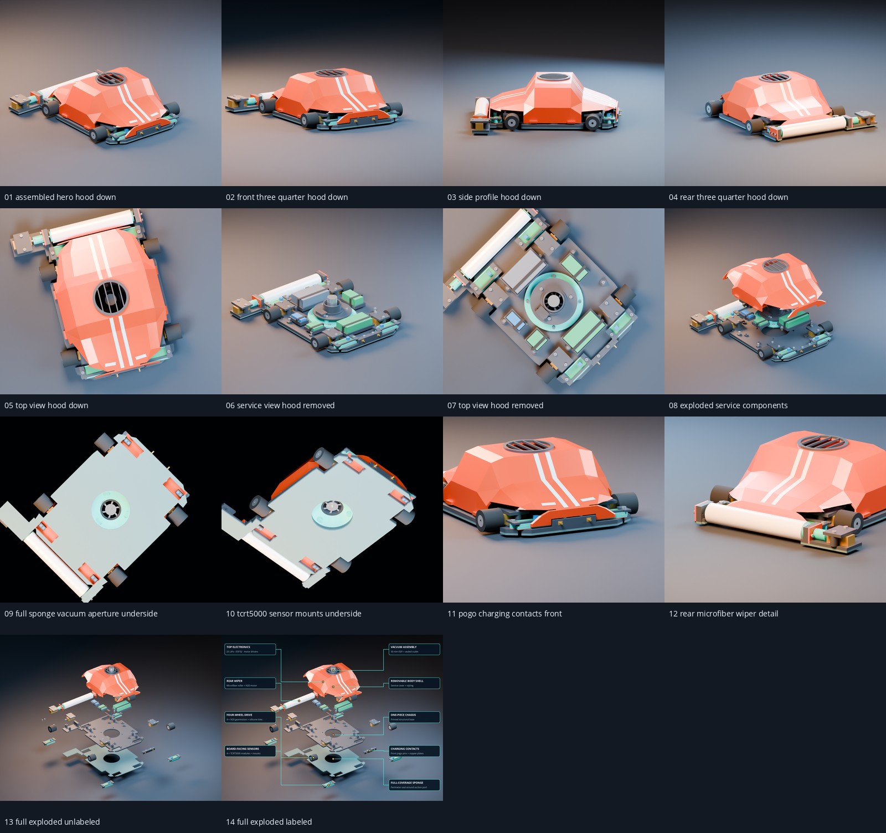
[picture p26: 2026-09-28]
renders/robot_views/contact_sheet.jpg

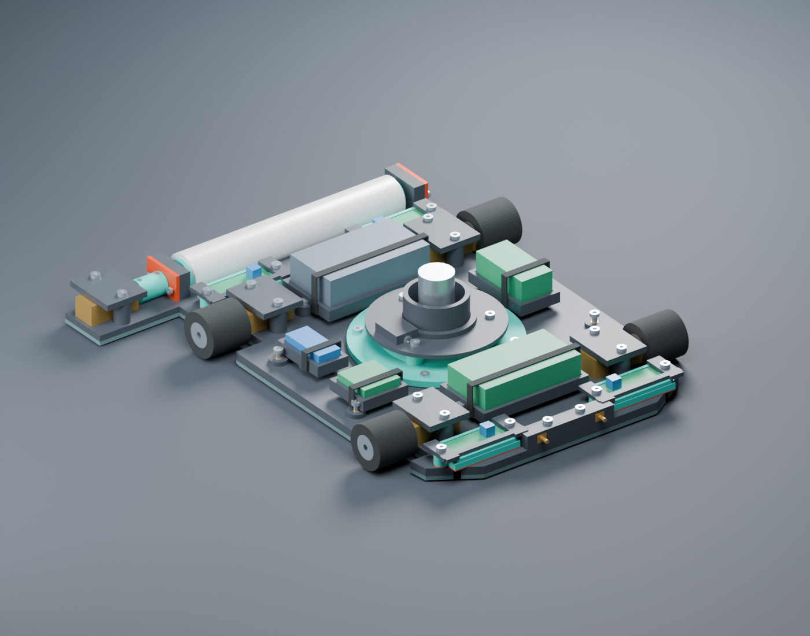
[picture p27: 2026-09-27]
robot_service.png

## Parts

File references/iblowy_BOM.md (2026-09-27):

# Bill of Materials

Total cost ~$150 CAD.

## Motors

| Part | Qty | Price (CAD) | Link |
|---|-----|---|---|
| 25GA-370 DC 12V 130RPM Motor + 65mm Wheel | 2 | ~$8 ea | [AliExpress](https://www.aliexpress.com/item/1005006213252744.html) |
| N20 Reduction Motor 12V ~200RPM | 2 | ~$5 ea | [AliExpress](https://www.aliexpress.com/item/1005007260112337.html) |
| A2212 1000KV Brushless Motor + 30A ESC | 1 | ~$15 | [AliExpress](https://www.aliexpress.com/item/1005006463223347.html) |

> Get the **KV1000 30A T-plug** variant to minimize soldering. Higher KV versions (e.g. 2000KV) probally work but produce significantly stronger suction, so be careful.
> Wheel encoders are **not required** for the current version.

## Electronics

| Part | Qty | Price (CAD) | Link |
|---|-----|---|---|
| L298N Motor Driver | 1 | ~$7 | [AliExpress](https://www.aliexpress.com/item/1005012534913417.html) |
| ESP32-WROOM-32E Dev Board | 1 | ~$20 | [Amazon](https://a.co/d/07teNxd0) |
| MOSFET Trigger Switch | 1 | ~$4 | [AliExpress](https://www.aliexpress.com/item/1005012000112180.html) |

## Power

| Part | Qty | Price (CAD) | Link |
|---|-----|---|---|
| 3S LiPo Battery | 1 | ~$42 | [Amazon](https://a.co/d/05lLGbFd) |

> This battery is overkill — the robot's discharge rate doesn't need it. A 3-cell 18650 pack is a cheaper alternative and should work just as well.

## Hardware & Filament

| Part | Qty | Price (CAD) | Link |
|---|-----|---|---|
| M3 Screw Assortment Box | 1 | ~$15 | [AliExpress](https://www.aliexpress.com/item/1005004833515587.html) |
| M1.6 x5mm Screws (N20 motor mounting) | 4 | — | [AliExpress](https://www.aliexpress.com/item/1005010018111061.html) |
| PETG Filament | ~700g | — | Any brand |

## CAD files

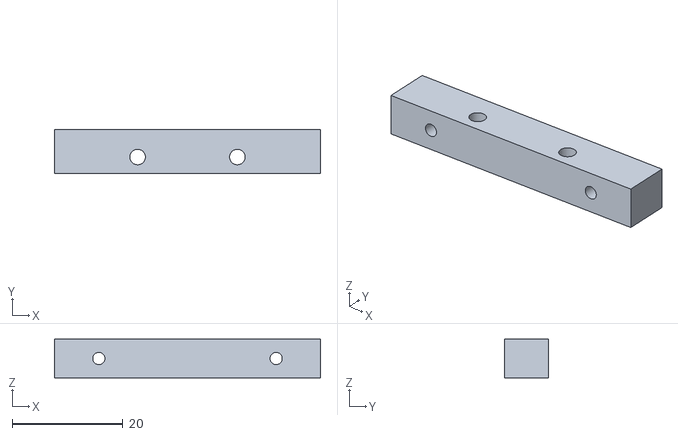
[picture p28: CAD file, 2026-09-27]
manufacturing/Charging_Contact_Block.stl
48.0 x 8.00 x 7.00

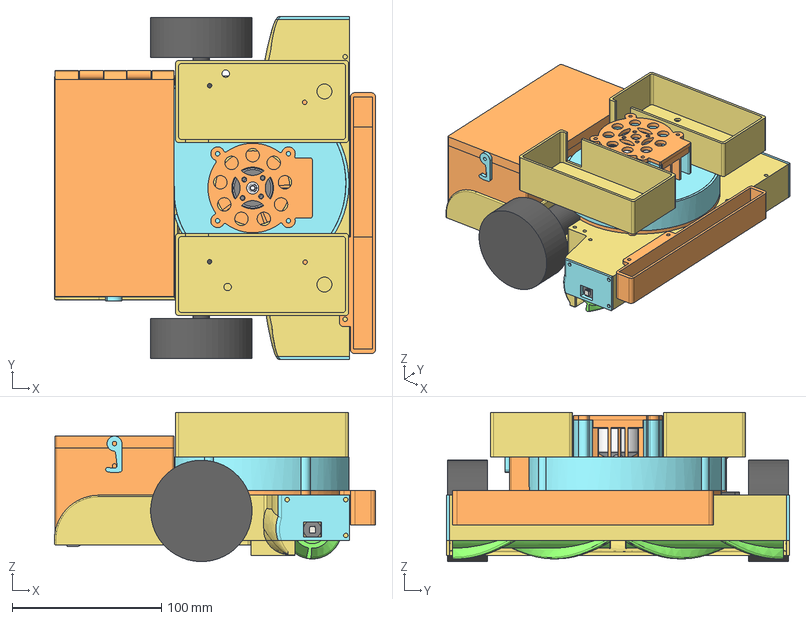
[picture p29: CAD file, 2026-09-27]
references/iblowy.step
215.5 x 230.0 x 100.1 mm
Motor_BLDC_2212,6T_2200KV
motor_with_wheel v1
motor_with_wheel v1 (1)
_N20-0002

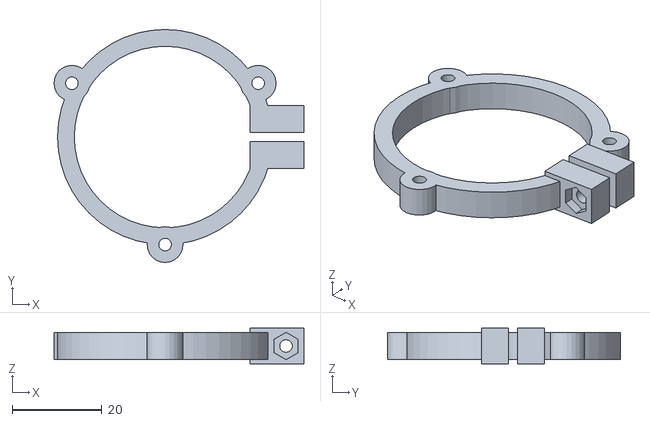
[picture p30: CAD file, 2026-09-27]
manufacturing/Blower_Base_Clamp.stl
55.8 x 52.0 x 8.00

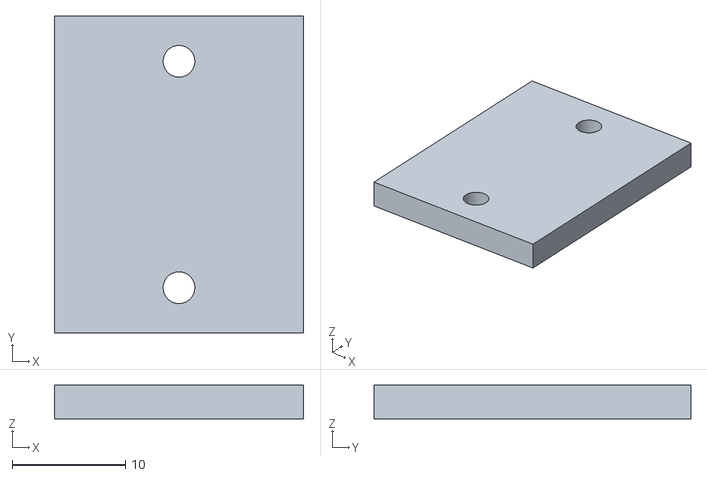
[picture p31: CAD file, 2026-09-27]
manufacturing/Wiper_Motor_Clamp.stl
22.0 x 28.0 x 3.00

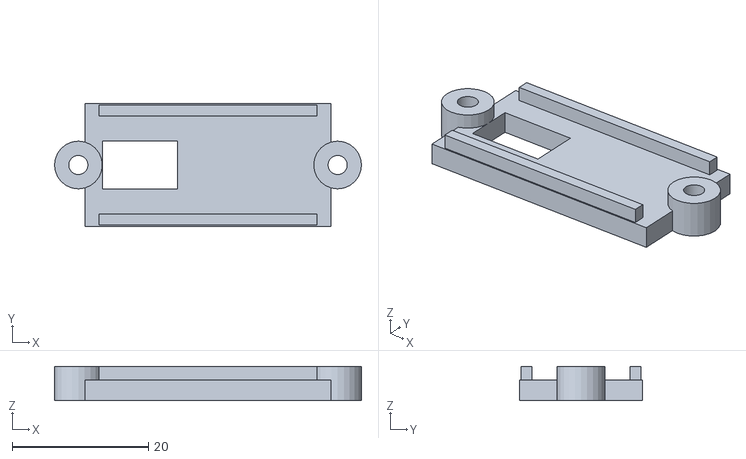
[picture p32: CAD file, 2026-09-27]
manufacturing/Sensor_Cartridge_Left_Rear.stl
45.0 x 18.0 x 5.00

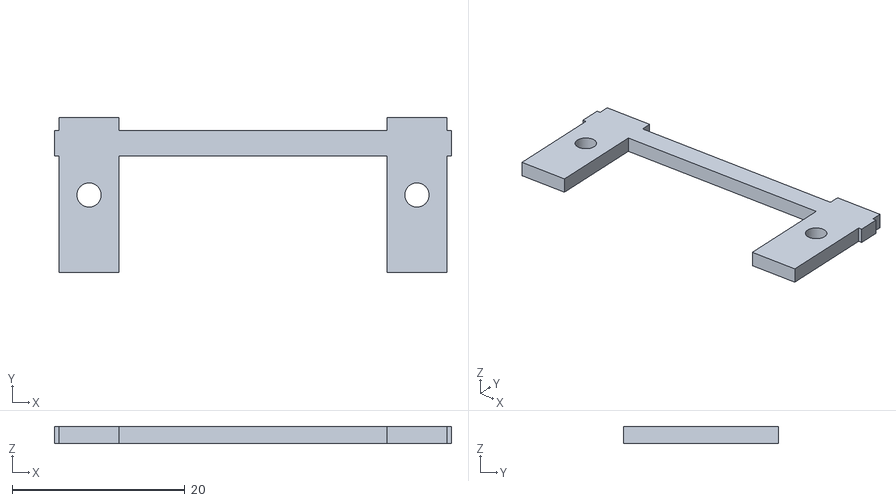
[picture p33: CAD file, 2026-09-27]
manufacturing/Sensor_Edge_Clamp_Right_Front.stl
46.0 x 18.0 x 2.00

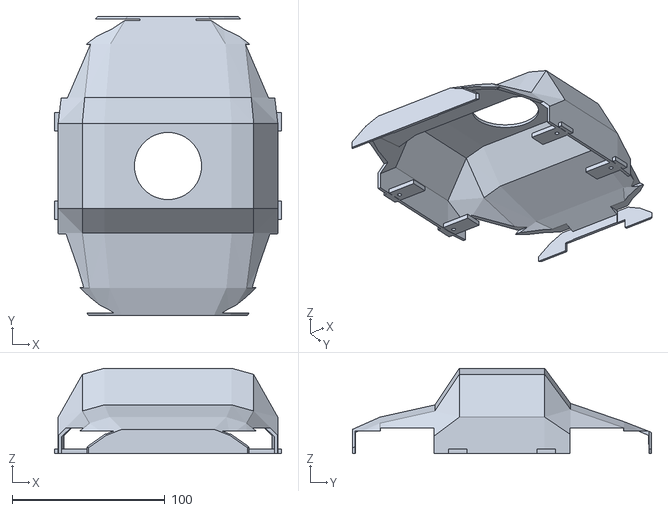
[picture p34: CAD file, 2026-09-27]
manufacturing/Sports_Car_Service_Cover.stl
149.0 x 196.0 x 56.0

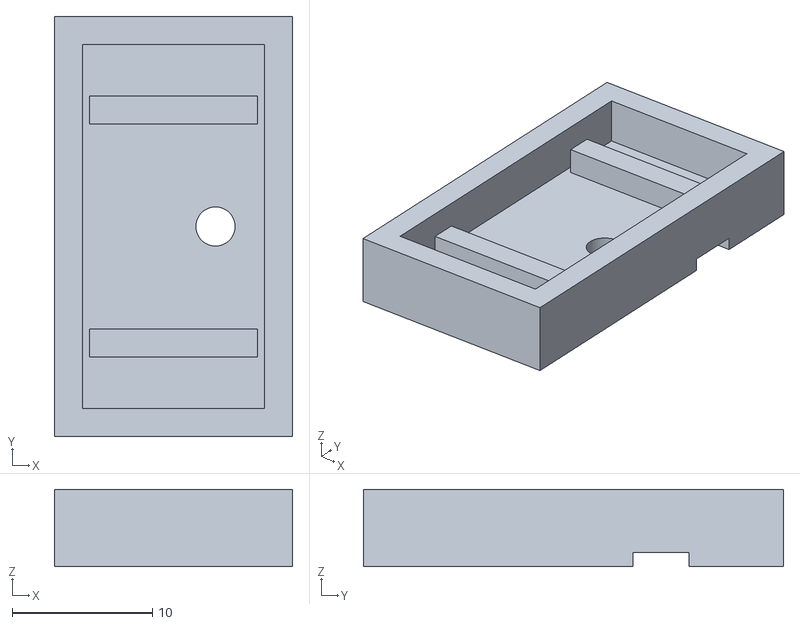
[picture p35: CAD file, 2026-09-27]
manufacturing/BLHeli_ESC_Tray.stl
17.0 x 30.0 x 5.50

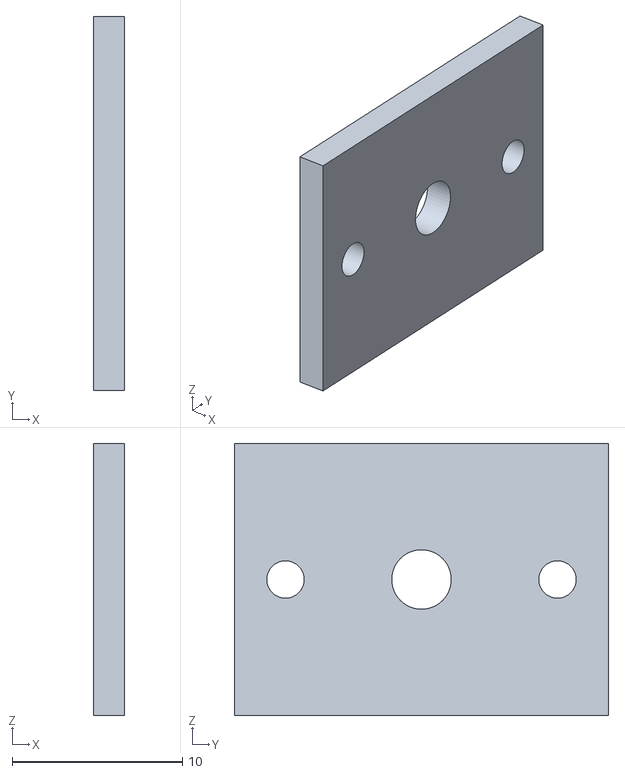
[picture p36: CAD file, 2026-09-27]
manufacturing/Bearing_Retainer_Left.stl
1.80 x 22.0 x 16.0

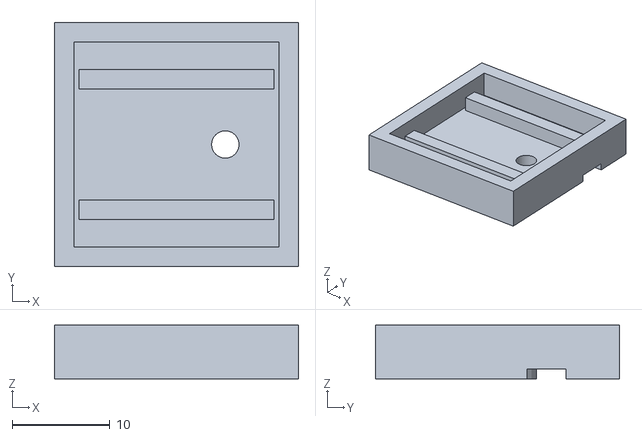
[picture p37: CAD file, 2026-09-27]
manufacturing/TB6612FNG_Tray.stl
25.0 x 25.0 x 5.50

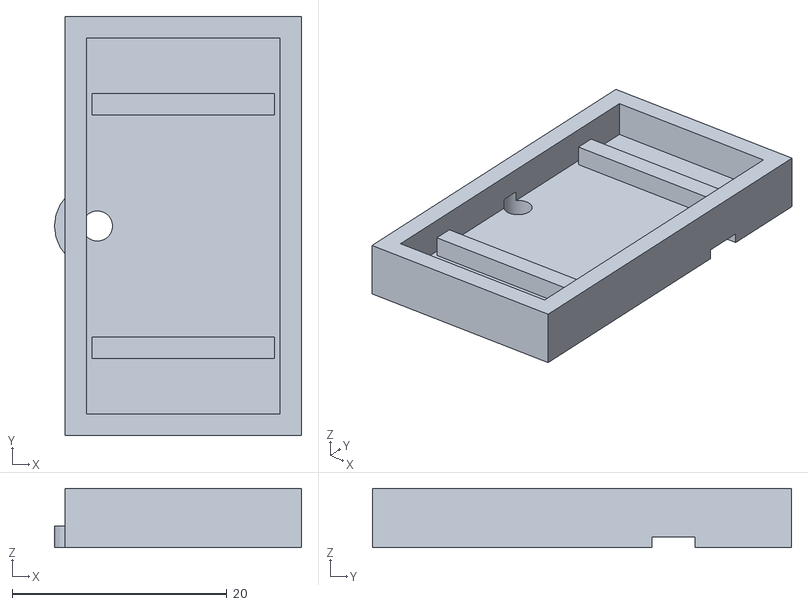
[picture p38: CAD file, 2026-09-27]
manufacturing/D4184_MOSFET_Tray.stl
23.0 x 39.0 x 5.50

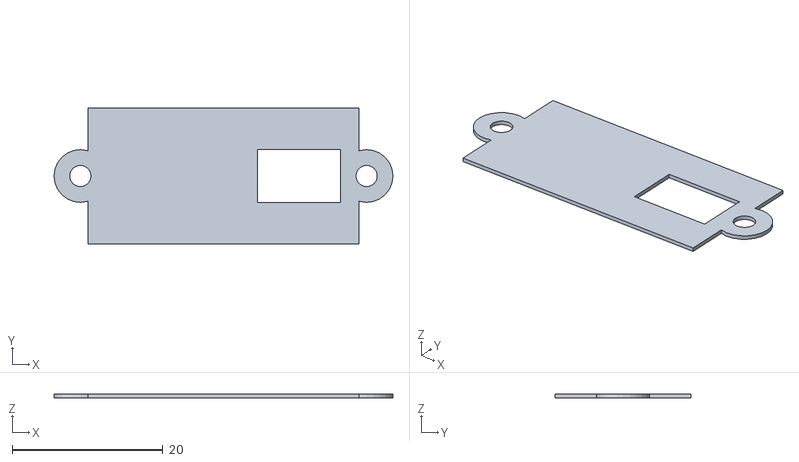
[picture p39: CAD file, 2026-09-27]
manufacturing/Sensor_Height_Shim_Right_Front.stl
45.0 x 18.0 x 0.5

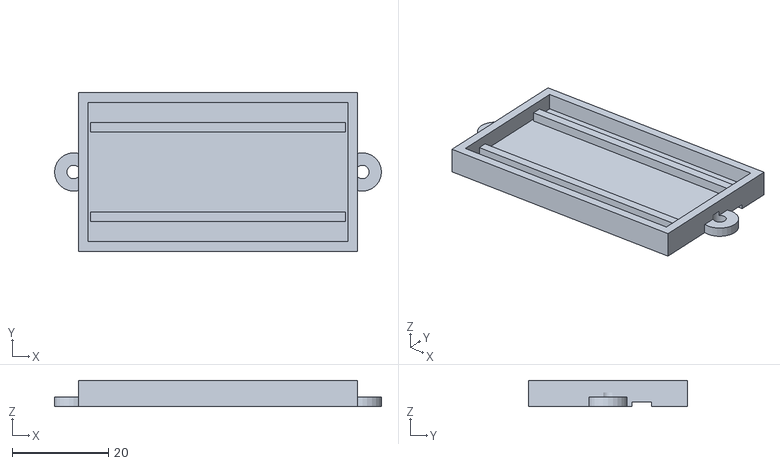
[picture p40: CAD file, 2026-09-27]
manufacturing/ESP32_S3_Tray.stl
68.0 x 33.0 x 5.50

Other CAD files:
manufacturing/Motor_Clamp_Left_Rear.stl
manufacturing/Sensor_Edge_Clamp_Left_Front.stl
manufacturing/Sensor_Edge_Clamp_Left_Rear.stl
manufacturing/Sensor_Cartridge_Right_Rear.stl
manufacturing/Sensor_Cartridge_Right_Front.stl
Vacuum_Robot_Blockout.blend
archive/blockout_v1/Vacuum_Robot_Blockout.blend
manufacturing/Battery_2S_LiPo_Tray.stl
manufacturing/Chassis.stl
manufacturing/EDF_Duct_Clamp.stl
manufacturing/Exhaust_Grille.stl
manufacturing/Motor_Clamp_Left_Front.stl
manufacturing/Motor_Clamp_Right_Front.stl
manufacturing/Motor_Clamp_Right_Rear.stl
manufacturing/Roller_Core.stl
manufacturing/Roller_Shaft_Coupling.stl
manufacturing/Sensor_Cartridge_Left_Front.stl
manufacturing/Sensor_Edge_Clamp_Right_Rear.stl
manufacturing/Sensor_Height_Shim_Left_Front.stl
manufacturing/Sensor_Height_Shim_Left_Rear.stl
manufacturing/Sensor_Height_Shim_Right_Rear.stl
manufacturing/Vacuum_Adapter.stl

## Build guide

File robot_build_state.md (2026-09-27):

# Vacuum Robot Build State

- Revision 2: assembly-oriented, sports-car-style prototype; not production qualified.
- Four 6 V N20 drive motors per user decision; PDF's two-motor configuration is superseded.
- Full-footprint 2 mm sponge follows the chassis and its rear extensions, with a 56 mm
  vacuum opening, wheel reliefs and four sensor windows.
- The chassis has a 56 mm port feeding a gasketed adapter and QX-Motor 30 mm axial EDF.
  QF1611 14000 KV is modeled to match the 2S battery; confirm the motor's printed KV.
  Seller dimensions do not define duct ID/length; modeled fit envelope remains provisional.
  The vendor's 19.3 A 2S test point exceeds the modeled 500 mAh 30C pack's 15 A rating.
- Wheel envelope remains 22 x 21 mm from original request; PDF provides no exact wheel SKU.
- All nominal shaft/hub axes align. Motor envelope is interpreted as 26 mm body + 10 mm shaft.
- One unified chassis includes insert towers, rear forks and sensor support bosses.
- New cover, clamps, trays and coupling are separate printable parts, parented to Chassis.
- Use real screws, inserts, a 3 mm roller axle and 623 bearings; electronics and elastomers
  are purchased. Shaft profiles, fits and purchased hardware must be checked on a prototype.
- The original 100 g chassis allowance is retained as an estimate, not a calculated weight.
  Added hardware/printed parts and the enlarged full pad have unknown masses (-1).
- Godot collision helpers are static inspection geometry (-colonly for apertured structures).
  They are not dynamic rigid-body-ready; use convex decomposition before rigid-body use.
- Manufacturing exports are mm STL fit prototypes. Validate selected parts, pad drag,
  sealing, suction pressure/flow and wheel traction before operating on a vertical board.

## Components

001. `Chassis` | mesh `Chassis_Mesh` | world dimensions mm (191.0000, 225.0000, 16.0000) | world origin mm (0.0000, 0.0000, 0.0000) | bounds mm (-76.0000, -125.0000, 2.0000) → (115.0000, 100.0000, 18.0000) | scale (1.0000, 1.0000, 1.0000) | mass g 100.0 | voltage V -1.0 | type Printed PETG part
002. `Full_Bottom_Sponge` | mesh `Full_Bottom_Sponge_Mesh` | world dimensions mm (191.0000, 222.0000, 2.0000) | world origin mm (0.0000, 0.0000, 0.0000) | bounds mm (-76.0000, -122.0000, -0.0000) → (115.0000, 100.0000, 2.0000) | scale (1.0000, 1.0000, 1.0000) | mass g -1.0 | voltage V -1.0 | type Die-cut closed-cell sponge pad
003. `Vacuum_Flange_Gasket` | mesh `Vacuum_Flange_Gasket_Mesh` | world dimensions mm (80.0000, 80.0000, 0.5000) | world origin mm (0.0000, 0.0000, 6.2500) | bounds mm (-40.0000, -40.0000, 6.0000) → (40.0000, 40.0000, 6.5000) | scale (1.0000, 1.0000, 1.0000) | mass g -1.0 | voltage V -1.0 | type Cut silicone gasket
004. `Vacuum_Adapter` | mesh `Vacuum_Adapter_Mesh` | world dimensions mm (80.0000, 80.0000, 10.0000) | world origin mm (0.0000, 0.0000, 11.5000) | bounds mm (-40.0000, -40.0000, 6.5000) → (40.0000, 40.0000, 16.5000) | scale (1.0000, 1.0000, 1.0000) | mass g -1.0 | voltage V -1.0 | type Printed PETG part
005. `Vacuum_Insert_-25_-25` | mesh `Vacuum_Insert_-25_-25_Mesh` | world dimensions mm (3.6000, 3.6000, 3.0000) | world origin mm (-25.0000, -25.0000, 4.5000) | bounds mm (-26.8000, -26.8000, 3.0000) → (-23.2000, -23.2000, 6.0000) | scale (1.0000, 1.0000, 1.0000) | mass g -1.0 | voltage V -1.0 | type Purchased M2.5 heat-set insert
006. `Vacuum_Flange_Screw_-25_-25` | mesh `Vacuum_Flange_Screw_-25_-25_Mesh` | world dimensions mm (4.5000, 4.5000, 7.6050) | world origin mm (-25.0000, -25.0000, 6.5000) | bounds mm (-27.2500, -27.2500, 3.5000) → (-22.7500, -22.7500, 11.1050) | scale (1.0000, 1.0000, 1.0000) | mass g -1.0 | voltage V -1.0 | type Purchased socket screw
007. `Vacuum_Insert_-25_25` | mesh `Vacuum_Insert_-25_25_Mesh` | world dimensions mm (3.6000, 3.6000, 3.0000) | world origin mm (-25.0000, 25.0000, 4.5000) | bounds mm (-26.8000, 23.2000, 3.0000) → (-23.2000, 26.8000, 6.0000) | scale (1.0000, 1.0000, 1.0000) | mass g -1.0 | voltage V -1.0 | type Purchased M2.5 heat-set insert
008. `Vacuum_Flange_Screw_-25_25` | mesh `Vacuum_Flange_Screw_-25_25_Mesh` | world dimensions mm (4.5000, 4.5000, 7.6050) | world origin mm (-25.0000, 25.0000, 6.5000) | bounds mm (-27.2500, 22.7500, 3.5000) → (-22.7500, 27.2500, 11.1050) | scale (1.0000, 1.0000, 1.0000) | mass g -1.0 | voltage V -1.0 | type Purchased socket screw
009. `Vacuum_Insert_25_-25` | mesh `Vacuum_Insert_25_-25_Mesh` | world dimensions mm (3.6000, 3.6000, 3.0000) | world origin mm (25.0000, -25.0000, 4.5000) | bounds mm (23.2000, -26.8000, 3.0000) → (26.8000, -23.2000, 6.0000) | scale (1.0000, 1.0000, 1.0000) | mass g -1.0 | voltage V -1.0 | type Purchased M2.5 heat-set insert
010. `Vacuum_Flange_Screw_25_-25` | mesh `Vacuum_Flange_Screw_25_-25_Mesh` | world dimensions mm (4.5000, 4.5000, 7.6050) | world origin mm (25.0000, -25.0000, 6.5000) | bounds mm (22.7500, -27.2500, 3.5000) → (27.2500, -22.7500, 11.1050) | scale (1.0000, 1.0000, 1.0000) | mass g -1.0 | voltage V -1.0 | type Purchased socket screw
011. `Vacuum_Insert_25_25` | mesh `Vacuum_Insert_25_25_Mesh` | world dimensions mm (3.6000, 3.6000, 3.0000) | world origin mm (25.0000, 25.0000, 4.5000) | bounds mm (23.2000, 23.2000, 3.0000) → (26.8000, 26.8000, 6.0000) | scale (1.0000, 1.0000, 1.0000) | mass g -1.0 | voltage V -1.0 | type Purchased M2.5 heat-set insert
012. `Vacuum_Flange_Screw_25_25` | mesh `Vacuum_Flange_Screw_25_25_Mesh` | world dimensions mm (4.5000, 4.5000, 7.6050) | world origin mm (25.0000, 25.0000, 6.5000) | bounds mm (22.7500, 22.7500, 3.5000) → (27.2500, 27.2500, 11.1050) | scale (1.0000, 1.0000, 1.0000) | mass g -1.0 | voltage V -1.0 | type Purchased socket screw
013. `EDF_Inlet_Gasket` | mesh `EDF_Inlet_Gasket_Mesh` | world dimensions mm (32.0000, 32.0000, 0.5000) | world origin mm (0.0000, 0.0000, 16.2500) | bounds mm (-16.0000, -16.0000, 16.0000) → (16.0000, 16.0000, 16.5000) | scale (1.0000, 1.0000, 1.0000) | mass g -1.0 | voltage V -1.0 | type Cut silicone EDF inlet gasket
014. `EDF_30mm_Duct_Stators` | mesh `EDF_30mm_Duct_Stators_Mesh` | world dimensions mm (30.0000, 30.0000, 16.0000) | world origin mm (0.0000, 0.0000, 24.5000) | bounds mm (-15.0000, -15.0000, 16.5000) → (15.0000, 15.0000, 32.5000) | scale (1.0000, 1.0000, 1.0000) | mass g 2.3 | voltage V 7.4 | type Purchased polycarbonate EDF casing
015. `EDF_Six_Blade_Impeller` | mesh `EDF_Six_Blade_Impeller_Mesh` | world dimensions mm (24.4664, 22.0325, 0.8000) | world origin mm (0.0000, 0.0000, 18.1500) | bounds mm (-12.2332, -11.0162, 17.7500) → (12.2332, 11.0162, 18.5500) | scale (1.0000, 1.0000, 1.0000) | mass g -1.0 | voltage V 7.4 | type Six-blade EDF rotor envelope
016. `QF1611_EDF_Motor` | mesh `QF1611_EDF_Motor_Mesh` | world dimensions mm (16.3000, 16.3000, 25.0000) | world origin mm (0.0000, 0.0000, 30.5000) | bounds mm (-8.1500, -8.1500, 18.0000) → (8.1500, 8.1500, 43.0000) | scale (1.0000, 1.0000, 1.0000) | mass g 19.5 | voltage V 7.4 | type QF1611 brushless motor
017. `QF1611_Output_Shaft` | mesh `QF1611_Output_Shaft_Mesh` | world dimensions mm (1.5000, 1.5000, 3.0000) | world origin mm (0.0000, 0.0000, 17.0000) | bounds mm (-0.7500, -0.7500, 15.5000) → (0.7500, 0.7500, 18.5000) | scale (1.0000, 1.0000, 1.0000) | mass g 0.0 | voltage V 7.4 | type QF1611 1.5 mm shaft envelope
018. `EDF_Duct_Clamp` | mesh `EDF_Duct_Clamp_Mesh` | world dimensions mm (64.0000, 64.0000, 8.0000) | world origin mm (0.0000, 0.0000, 19.0000) | bounds mm (-32.0000, -32.0000, 15.0000) → (32.0000, 32.0000, 23.0000) | scale (1.0000, 1.0000, 1.0000) | mass g -1.0 | voltage V -1.0 | type Printed PETG part
019. `EDF_Duct_Pinch_Screw` | mesh `EDF_Duct_Pinch_Screw_Mesh` | world dimensions mm (4.5000, 15.6050, 4.5000) | world origin mm (22.0000, 0.0000, 19.0000) | bounds mm (19.7500, -7.0000, 16.7500) → (24.2500, 8.6050, 21.2500) | scale (1.0000, 1.0000, 1.0000) | mass g -1.0 | voltage V -1.0 | type Purchased socket screw
020. `EDF_Duct_Pinch_Nut` | mesh `EDF_Duct_Pinch_Nut_Mesh` | world dimensions mm (5.0229, 2.0000, 5.8000) | world origin mm (22.0000, -5.3000, 19.0000) | bounds mm (19.4885, -6.3000, 16.1000) → (24.5115, -4.3000, 21.9000) | scale (1.0000, 1.0000, 1.0000) | mass g -1.0 | voltage V -1.0 | type Purchased M2.5 hex nut
021. `EDF_Clamp_Screw_30` | mesh `EDF_Clamp_Screw_30_Mesh` | world dimensions mm (4.5000, 4.5000, 7.6050) | world origin mm (20.7846, 12.0000, 15.5000) | bounds mm (18.5346, 9.7500, 12.5000) → (23.0346, 14.2500, 20.1050) | scale (1.0000, 1.0000, 1.0000) | mass g -1.0 | voltage V -1.0 | type Purchased socket screw
022. `EDF_Clamp_Screw_150` | mesh `EDF_Clamp_Screw_150_Mesh` | world dimensions mm (4.5000, 4.5000, 7.6050) | world origin mm (-20.7846, 12.0000, 15.5000) | bounds mm (-23.0346, 9.7500, 12.5000) → (-18.5346, 14.2500, 20.1050) | scale (1.0000, 1.0000, 1.0000) | mass g -1.0 | voltage V -1.0 | type Purchased socket screw
023. `EDF_Clamp_Screw_270` | mesh `EDF_Clamp_Screw_270_Mesh` | world dimensions mm (4.5000, 4.5000, 7.6050) | world origin mm (-0.0000, -24.0000, 15.5000) | bounds mm (-2.2500, -26.2500, 12.5000) → (2.2500, -21.7500, 20.1050) | scale (1.0000, 1.0000, 1.0000) | mass g -1.0 | voltage V -1.0 | type Purchased socket screw
024. `Drive_Motor_Left_Front` | mesh `Drive_Motor_Left_Front_Mesh` | world dimensions mm (26.0000, 12.0000, 10.0000) | world origin mm (-50.5000, 62.0000, 11.0000) | bounds mm (-63.5000, 56.0000, 6.0000) → (-37.5000, 68.0000, 16.0000) | scale (1.0000, 1.0000, 1.0000) | mass g 10.0 | voltage V 6.0 | type N20 geared motor envelope
025. `Drive_Shaft_Left_Front` | mesh `Drive_Shaft_Left_Front_Mesh` | world dimensions mm (10.0000, 3.0000, 3.0000) | world origin mm (-68.5000, 62.0000, 11.0000) | bounds mm (-73.5000, 60.5000, 9.5000) → (-63.5000, 63.5000, 12.5000) | scale (1.0000, 1.0000, 1.0000) | mass g 0.0 | voltage V 6.0 | type N20 output shaft
026. `Wheel_Tire_Left_Front` | mesh `Wheel_Tire_Left_Front_Mesh` | world dimensions mm (21.0000, 22.0000, 22.0000) | world origin mm (-75.0000, 62.0000, 11.0000) | bounds mm (-85.5000, 51.0000, 0.0000) → (-64.5000, 73.0000, 22.0000) | scale (1.0000, 1.0000, 1.0000) | mass g 5.0 | voltage V -1.0 | type Shore 20A silicone tire
027. `Wheel_Hub_Left_Front` | mesh `Wheel_Hub_Left_Front_Mesh` | world dimensions mm (21.0000, 12.0000, 12.0000) | world origin mm (-75.0000, 62.0000, 11.0000) | bounds mm (-85.5000, 56.0000, 5.0000) → (-64.5000, 68.0000, 17.0000) | scale (1.0000, 1.0000, 1.0000) | mass g 2.5 | voltage V -1.0 | type Aluminum wheel hub envelope
028. `Hub_SetScrew_Left_Front` | mesh `Hub_SetScrew_Left_Front_Mesh` | world dimensions mm (2.5000, 2.5000, 5.0000) | world origin mm (-70.0000, 62.0000, 14.5000) | bounds mm (-71.2500, 60.7500, 12.0000) → (-68.7500, 63.2500, 17.0000) | scale (1.0000, 1.0000, 1.0000) | mass g -1.0 | voltage V -1.0 | type Purchased socket screw
029. `Motor_Clamp_Left_Front` | mesh `Motor_Clamp_Left_Front_Mesh` | world dimensions mm (22.0000, 28.0000, 3.0000) | world origin mm (-49.0000, 62.0000, 17.9000) | bounds mm (-60.0000, 48.0000, 16.4000) → (-38.0000, 76.0000, 19.4000) | scale (1.0000, 1.0000, 1.0000) | mass g -1.0 | voltage V -1.0 | type Printed PETG part
030. `Motor_Clamp_Pad_Left_Front` | mesh `Motor_Clamp_Pad_Left_Front_Mesh` | world dimensions mm (20.0000, 12.0000, 0.4000) | world origin mm (-49.0000, 62.0000, 16.2000) | bounds mm (-59.0000, 56.0000, 16.0000) → (-39.0000, 68.0000, 16.4000) | scale (1.0000, 1.0000, 1.0000) | mass g -1.0 | voltage V -1.0 | type Thin compliant clamp pad
031. `Motor_Insert_Left_Front-10` | mesh `Motor_Insert_Left_Front-10_Mesh` | world dimensions mm (3.6000, 3.6000, 4.0000) | world origin mm (-49.0000, 52.0000, 14.3500) | bounds mm (-50.8000, 50.2000, 12.3500) → (-47.2000, 53.8000, 16.3500) | scale (1.0000, 1.0000, 1.0000) | mass g -1.0 | voltage V -1.0 | type Purchased M2.5 heat-set insert
032. `Motor_Screw_Left_Front-10` | mesh `Motor_Screw_Left_Front-10_Mesh` | world dimensions mm (4.5000, 4.5000, 9.6050) | world origin mm (-49.0000, 52.0000, 15.4000) | bounds mm (-51.2500, 49.7500, 11.4000) → (-46.7500, 54.2500, 21.0050) | scale (1.0000, 1.0000, 1.0000) | mass g -1.0 | voltage V -1.0 | type Purchased socket screw
033. `Motor_Insert_Left_Front10` | mesh `Motor_Insert_Left_Front10_Mesh` | world dimensions mm (3.6000, 3.6000, 4.0000) | world origin mm (-49.0000, 72.0000, 14.3500) | bounds mm (-50.8000, 70.2000, 12.3500) → (-47.2000, 73.8000, 16.3500) | scale (1.0000, 1.0000, 1.0000) | mass g -1.0 | voltage V -1.0 | type Purchased M2.5 heat-set insert
034. `Motor_Screw_Left_Front10` | mesh `Motor_Screw_Left_Front10_Mesh` | world dimensions mm (4.5000, 4.5000, 9.6050) | world origin mm (-49.0000, 72.0000, 15.4000) | bounds mm (-51.2500, 69.7500, 11.4000) → (-46.7500, 74.2500, 21.0050) | scale (1.0000, 1.0000, 1.0000) | mass g -1.0 | voltage V -1.0 | type Purchased socket screw
035. `Drive_Motor_Left_Rear` | mesh `Drive_Motor_Left_Rear_Mesh` | world dimensions mm (26.0000, 12.0000, 10.0000) | world origin mm (-50.5000, -62.0000, 11.0000) | bounds mm (-63.5000, -68.0000, 6.0000) → (-37.5000, -56.0000, 16.0000) | scale (1.0000, 1.0000, 1.0000) | mass g 10.0 | voltage V 6.0 | type N20 geared motor envelope
036. `Drive_Shaft_Left_Rear` | mesh `Drive_Shaft_Left_Rear_Mesh` | world dimensions mm (10.0000, 3.0000, 3.0000) | world origin mm (-68.5000, -62.0000, 11.0000) | bounds mm (-73.5000, -63.5000, 9.5000) → (-63.5000, -60.5000, 12.5000) | scale (1.0000, 1.0000, 1.0000) | mass g 0.0 | voltage V 6.0 | type N20 output shaft
037. `Wheel_Tire_Left_Rear` | mesh `Wheel_Tire_Left_Rear_Mesh` | world dimensions mm (21.0000, 22.0000, 22.0000) | world origin mm (-75.0000, -62.0000, 11.0000) | bounds mm (-85.5000, -73.0000, 0.0000) → (-64.5000, -51.0000, 22.0000) | scale (1.0000, 1.0000, 1.0000) | mass g 5.0 | voltage V -1.0 | type Shore 20A silicone tire
038. `Wheel_Hub_Left_Rear` | mesh `Wheel_Hub_Left_Rear_Mesh` | world dimensions mm (21.0000, 12.0000, 12.0000) | world origin mm (-75.0000, -62.0000, 11.0000) | bounds mm (-85.5000, -68.0000, 5.0000) → (-64.5000, -56.0000, 17.0000) | scale (1.0000, 1.0000, 1.0000) | mass g 2.5 | voltage V -1.0 | type Aluminum wheel hub envelope
039. `Hub_SetScrew_Left_Rear` | mesh `Hub_SetScrew_Left_Rear_Mesh` | world dimensions mm (2.5000, 2.5000, 5.0000) | world origin mm (-70.0000, -62.0000, 14.5000) | bounds mm (-71.2500, -63.2500, 12.0000) → (-68.7500, -60.7500, 17.0000) | scale (1.0000, 1.0000, 1.0000) | mass g -1.0 | voltage V -1.0 | type Purchased socket screw
040. `Motor_Clamp_Left_Rear` | mesh `Motor_Clamp_Left_Rear_Mesh` | world dimensions mm (22.0000, 28.0000, 3.0000) | world origin mm (-49.0000, -62.0000, 17.9000) | bounds mm (-60.0000, -76.0000, 16.4000) → (-38.0000, -48.0000, 19.4000) | scale (1.0000, 1.0000, 1.0000) | mass g -1.0 | voltage V -1.0 | type Printed PETG part
041. `Motor_Clamp_Pad_Left_Rear` | mesh `Motor_Clamp_Pad_Left_Rear_Mesh` | world dimensions mm (20.0000, 12.0000, 0.4000) | world origin mm (-49.0000, -62.0000, 16.2000) | bounds mm (-59.0000, -68.0000, 16.0000) → (-39.0000, -56.0000, 16.4000) | scale (1.0000, 1.0000, 1.0000) | mass g -1.0 | voltage V -1.0 | type Thin compliant clamp pad
042. `Motor_Insert_Left_Rear-10` | mesh `Motor_Insert_Left_Rear-10_Mesh` | world dimensions mm (3.6000, 3.6000, 4.0000) | world origin mm (-49.0000, -72.0000, 14.3500) | bounds mm (-50.8000, -73.8000, 12.3500) → (-47.2000, -70.2000, 16.3500) | scale (1.0000, 1.0000, 1.0000) | mass g -1.0 | voltage V -1.0 | type Purchased M2.5 heat-set insert
043. `Motor_Screw_Left_Rear-10` | mesh `Motor_Screw_Left_Rear-10_Mesh` | world dimensions mm (4.5000, 4.5000, 9.6050) | world origin mm (-49.0000, -72.0000, 15.4000) | bounds mm (-51.2500, -74.2500, 11.4000) → (-46.7500, -69.7500, 21.0050) | scale (1.0000, 1.0000, 1.0000) | mass g -1.0 | voltage V -1.0 | type Purchased socket screw
044. `Motor_Insert_Left_Rear10` | mesh `Motor_Insert_Left_Rear10_Mesh` | world dimensions mm (3.6000, 3.6000, 4.0000) | world origin mm (-49.0000, -52.0000, 14.3500) | bounds mm (-50.8000, -53.8000, 12.3500) → (-47.2000, -50.2000, 16.3500) | scale (1.0000, 1.0000, 1.0000) | mass g -1.0 | voltage V -1.0 | type Purchased M2.5 heat-set insert
045. `Motor_Screw_Left_Rear10` | mesh `Motor_Screw_Left_Rear10_Mesh` | world dimensions mm (4.5000, 4.5000, 9.6050) | world origin mm (-49.0000, -52.0000, 15.4000) | bounds mm (-51.2500, -54.2500, 11.4000) → (-46.7500, -49.7500, 21.0050) | scale (1.0000, 1.0000, 1.0000) | mass g -1.0 | voltage V -1.0 | type Purchased socket screw
046. `Drive_Motor_Right_Front` | mesh `Drive_Motor_Right_Front_Mesh` | world dimensions mm (26.0000, 12.0000, 10.0000) | world origin mm (50.5000, 62.0000, 11.0000) | bounds mm (37.5000, 56.0000, 6.0000) → (63.5000, 68.0000, 16.0000) | scale (1.0000, 1.0000, 1.0000) | mass g 10.0 | voltage V 6.0 | type N20 geared motor envelope
047. `Drive_Shaft_Right_Front` | mesh `Drive_Shaft_Right_Front_Mesh` | world dimensions mm (10.0000, 3.0000, 3.0000) | world origin mm (68.5000, 62.0000, 11.0000) | bounds mm (63.5000, 60.5000, 9.5000) → (73.5000, 63.5000, 12.5000) | scale (1.0000, 1.0000, 1.0000) | mass g 0.0 | voltage V 6.0 | type N20 output shaft
048. `Wheel_Tire_Right_Front` | mesh `Wheel_Tire_Right_Front_Mesh` | world dimensions mm (21.0000, 22.0000, 22.0000) | world origin mm (75.0000, 62.0000, 11.0000) | bounds mm (64.5000, 51.0000, 0.0000) → (85.5000, 73.0000, 22.0000) | scale (1.0000, 1.0000, 1.0000) | mass g 5.0 | voltage V -1.0 | type Shore 20A silicone tire
049. `Wheel_Hub_Right_Front` | mesh `Wheel_Hub_Right_Front_Mesh` | world dimensions mm (21.0000, 12.0000, 12.0000) | world origin mm (75.0000, 62.0000, 11.0000) | bounds mm (64.5000, 56.0000, 5.0000) → (85.5000, 68.0000, 17.0000) | scale (1.0000, 1.0000, 1.0000) | mass g 2.5 | voltage V -1.0 | type Aluminum wheel hub envelope
050. `Hub_SetScrew_Right_Front` | mesh `Hub_SetScrew_Right_Front_Mesh` | world dimensions mm (2.5000, 2.5000, 5.0000) | world origin mm (70.0000, 62.0000, 14.5000) | bounds mm (68.7500, 60.7500, 12.0000) → (71.2500, 63.2500, 17.0000) | scale (1.0000, 1.0000, 1.0000) | mass g -1.0 | voltage V -1.0 | type Purchased socket screw
051. `Motor_Clamp_Right_Front` | mesh `Motor_Clamp_Right_Front_Mesh` | world dimensions mm (22.0000, 28.0000, 3.0000) | world origin mm (49.0000, 62.0000, 17.9000) | bounds mm (38.0000, 48.0000, 16.4000) → (60.0000, 76.0000, 19.4000) | scale (1.0000, 1.0000, 1.0000) | mass g -1.0 | voltage V -1.0 | type Printed PETG part
052. `Motor_Clamp_Pad_Right_Front` | mesh `Motor_Clamp_Pad_Right_Front_Mesh` | world dimensions mm (20.0000, 12.0000, 0.4000) | world origin mm (49.0000, 62.0000, 16.2000) | bounds mm (39.0000, 56.0000, 16.0000) → (59.0000, 68.0000, 16.4000) | scale (1.0000, 1.0000, 1.0000) | mass g -1.0 | voltage V -1.0 | type Thin compliant clamp pad
053. `Motor_Insert_Right_Front-10` | mesh `Motor_Insert_Right_Front-10_Mesh` | world dimensions mm (3.6000, 3.6000, 4.0000) | world origin mm (49.0000, 52.0000, 14.3500) | bounds mm (47.2000, 50.2000, 12.3500) → (50.8000, 53.8000, 16.3500) | scale (1.0000, 1.0000, 1.0000) | mass g -1.0 | voltage V -1.0 | type Purchased M2.5 heat-set insert
054. `Motor_Screw_Right_Front-10` | mesh `Motor_Screw_Right_Front-10_Mesh` | world dimensions mm (4.5000, 4.5000, 9.6050) | world origin mm (49.0000, 52.0000, 15.4000) | bounds mm (46.7500, 49.7500, 11.4000) → (51.2500, 54.2500, 21.0050) | scale (1.0000, 1.0000, 1.0000) | mass g -1.0 | voltage V -1.0 | type Purchased socket screw
055. `Motor_Insert_Right_Front10` | mesh `Motor_Insert_Right_Front10_Mesh` | world dimensions mm (3.6000, 3.6000, 4.0000) | world origin mm (49.0000, 72.0000, 14.3500) | bounds mm (47.2000, 70.2000, 12.3500) → (50.8000, 73.8000, 16.3500) | scale (1.0000, 1.0000, 1.0000) | mass g -1.0 | voltage V -1.0 | type Purchased M2.5 heat-set insert
056. `Motor_Screw_Right_Front10` | mesh `Motor_Screw_Right_Front10_Mesh` | world dimensions mm (4.5000, 4.5000, 9.6050) | world origin mm (49.0000, 72.0000, 15.4000) | bounds mm (46.7500, 69.7500, 11.4000) → (51.2500, 74.2500, 21.0050) | scale (1.0000, 1.0000, 1.0000) | mass g -1.0 | voltage V -1.0 | type Purchased socket screw
057. `Drive_Motor_Right_Rear` | mesh `Drive_Motor_Right_Rear_Mesh` | world dimensions mm (26.0000, 12.0000, 10.0000) | world origin mm (50.5000, -62.0000, 11.0000) | bounds mm (37.5000, -68.0000, 6.0000) → (63.5000, -56.0000, 16.0000) | scale (1.0000, 1.0000, 1.0000) | mass g 10.0 | voltage V 6.0 | type N20 geared motor envelope
058. `Drive_Shaft_Right_Rear` | mesh `Drive_Shaft_Right_Rear_Mesh` | world dimensions mm (10.0000, 3.0000, 3.0000) | world origin mm (68.5000, -62.0000, 11.0000) | bounds mm (63.5000, -63.5000, 9.5000) → (73.5000, -60.5000, 12.5000) | scale (1.0000, 1.0000, 1.0000) | mass g 0.0 | voltage V 6.0 | type N20 output shaft
059. `Wheel_Tire_Right_Rear` | mesh `Wheel_Tire_Right_Rear_Mesh` | world dimensions mm (21.0000, 22.0000, 22.0000) | world origin mm (75.0000, -62.0000, 11.0000) | bounds mm (64.5000, -73.0000, 0.0000) → (85.5000, -51.0000, 22.0000) | scale (1.0000, 1.0000, 1.0000) | mass g 5.0 | voltage V -1.0 | type Shore 20A silicone tire
060. `Wheel_Hub_Right_Rear` | mesh `Wheel_Hub_Right_Rear_Mesh` | world dimensions mm (21.0000, 12.0000, 12.0000) | world origin mm (75.0000, -62.0000, 11.0000) | bounds mm (64.5000, -68.0000, 5.0000) → (85.5000, -56.0000, 17.0000) | scale (1.0000, 1.0000, 1.0000) | mass g 2.5 | voltage V -1.0 | type Aluminum wheel hub envelope
061. `Hub_SetScrew_Right_Rear` | mesh `Hub_SetScrew_Right_Rear_Mesh` | world dimensions mm (2.5000, 2.5000, 5.0000) | world origin mm (70.0000, -62.0000, 14.5000) | bounds mm (68.7500, -63.2500, 12.0000) → (71.2500, -60.7500, 17.0000) | scale (1.0000, 1.0000, 1.0000) | mass g -1.0 | voltage V -1.0 | type Purchased socket screw
062. `Motor_Clamp_Right_Rear` | mesh `Motor_Clamp_Right_Rear_Mesh` | world dimensions mm (22.0000, 28.0000, 3.0000) | world origin mm (49.0000, -62.0000, 17.9000) | bounds mm (38.0000, -76.0000, 16.4000) → (60.0000, -48.0000, 19.4000) | scale (1.0000, 1.0000, 1.0000) | mass g -1.0 | voltage V -1.0 | type Printed PETG part
063. `Motor_Clamp_Pad_Right_Rear` | mesh `Motor_Clamp_Pad_Right_Rear_Mesh` | world dimensions mm (20.0000, 12.0000, 0.4000) | world origin mm (49.0000, -62.0000, 16.2000) | bounds mm (39.0000, -68.0000, 16.0000) → (59.0000, -56.0000, 16.4000) | scale (1.0000, 1.0000, 1.0000) | mass g -1.0 | voltage V -1.0 | type Thin compliant clamp pad
064. `Motor_Insert_Right_Rear-10` | mesh `Motor_Insert_Right_Rear-10_Mesh` | world dimensions mm (3.6000, 3.6000, 4.0000) | world origin mm (49.0000, -72.0000, 14.3500) | bounds mm (47.2000, -73.8000, 12.3500) → (50.8000, -70.2000, 16.3500) | scale (1.0000, 1.0000, 1.0000) | mass g -1.0 | voltage V -1.0 | type Purchased M2.5 heat-set insert
065. `Motor_Screw_Right_Rear-10` | mesh `Motor_Screw_Right_Rear-10_Mesh` | world dimensions mm (4.5000, 4.5000, 9.6050) | world origin mm (49.0000, -72.0000, 15.4000) | bounds mm (46.7500, -74.2500, 11.4000) → (51.2500, -69.7500, 21.0050) | scale (1.0000, 1.0000, 1.0000) | mass g -1.0 | voltage V -1.0 | type Purchased socket screw
066. `Motor_Insert_Right_Rear10` | mesh `Motor_Insert_Right_Rear10_Mesh` | world dimensions mm (3.6000, 3.6000, 4.0000) | world origin mm (49.0000, -52.0000, 14.3500) | bounds mm (47.2000, -53.8000, 12.3500) → (50.8000, -50.2000, 16.3500) | scale (1.0000, 1.0000, 1.0000) | mass g -1.0 | voltage V -1.0 | type Purchased M2.5 heat-set insert
067. `Motor_Screw_Right_Rear10` | mesh `Motor_Screw_Right_Rear10_Mesh` | world dimensions mm (4.5000, 4.5000, 9.6050) | world origin mm (49.0000, -52.0000, 15.4000) | bounds mm (46.7500, -54.2500, 11.4000) → (51.2500, -49.7500, 21.0050) | scale (1.0000, 1.0000, 1.0000) | mass g -1.0 | voltage V -1.0 | type Purchased socket screw
068. `Roller_Core` | mesh `Roller_Core_Mesh` | world dimensions mm (120.0000, 15.0000, 15.0000) | world origin mm (0.0000, -111.0000, 10.0000) | bounds mm (-60.0000, -118.5000, 2.5000) → (60.0000, -103.5000, 17.5000) | scale (1.0000, 1.0000, 1.0000) | mass g -1.0 | voltage V -1.0 | type Printed PETG part
069. `Microfiber_Roller` | mesh `Microfiber_Roller_Mesh` | world dimensions mm (116.0000, 20.0000, 20.0000) | world origin mm (0.0000, -111.0000, 10.0000) | bounds mm (-58.0000, -121.0000, -0.0000) → (58.0000, -101.0000, 20.0000) | scale (1.0000, 1.0000, 1.0000) | mass g 5.0 | voltage V -1.0 | type Replaceable microfiber sleeve
070. `Roller_Steel_Axle` | mesh `Roller_Steel_Axle_Mesh` | world dimensions mm (146.0000, 3.0000, 3.0000) | world origin mm (0.0000, -111.0000, 10.0000) | bounds mm (-73.0000, -112.5000, 8.5000) → (73.0000, -109.5000, 11.5000) | scale (1.0000, 1.0000, 1.0000) | mass g -1.0 | voltage V -1.0 | type Purchased 3 mm steel axle
071. `Roller_Bearing_Left` | mesh `Roller_Bearing_Left_Mesh` | world dimensions mm (4.0000, 10.0000, 10.0000) | world origin mm (-66.0000, -111.0000, 10.0000) | bounds mm (-68.0000, -116.0000, 5.0000) → (-64.0000, -106.0000, 15.0000) | scale (1.0000, 1.0000, 1.0000) | mass g -1.0 | voltage V -1.0 | type Purchased 623 bearing 3 x 10 x 4
072. `Bearing_Retainer_Left` | mesh `Bearing_Retainer_Left_Mesh` | world dimensions mm (1.8000, 22.0000, 16.0000) | world origin mm (-68.9000, -111.0000, 10.0000) | bounds mm (-69.8000, -122.0000, 2.0000) → (-68.0000, -100.0000, 18.0000) | scale (1.0000, 1.0000, 1.0000) | mass g -1.0 | voltage V -1.0 | type Printed PETG part
073. `Bearing_Screw_Left-119` | mesh `Bearing_Screw_Left-119_Mesh` | world dimensions mm (8.2800, 3.6000, 3.6000) | world origin mm (67.3000, -119.0000, 10.0000) | bounds mm (63.8000, -120.8000, 8.2000) → (72.0800, -117.2000, 11.8000) | scale (1.0000, 1.0000, 1.0000) | mass g -1.0 | voltage V -1.0 | type Purchased socket screw
074. `Bearing_Screw_Left-119` | mesh `Bearing_Screw_Left-119_Mesh` | world dimensions mm (8.2800, 3.6000, 3.6000) | world origin mm (-67.3000, -119.0000, 10.0000) | bounds mm (-72.0800, -120.8000, 8.2000) → (-63.8000, -117.2000, 11.8000) | scale (1.0000, 1.0000, 1.0000) | mass g -1.0 | voltage V -1.0 | type Purchased socket screw
075. `Bearing_Screw_Left-103` | mesh `Bearing_Screw_Left-103_Mesh` | world dimensions mm (8.2800, 3.6000, 3.6000) | world origin mm (67.3000, -103.0000, 10.0000) | bounds mm (63.8000, -104.8000, 8.2000) → (72.0800, -101.2000, 11.8000) | scale (1.0000, 1.0000, 1.0000) | mass g -1.0 | voltage V -1.0 | type Purchased socket screw
076. `Bearing_Screw_Left-103` | mesh `Bearing_Screw_Left-103_Mesh` | world dimensions mm (8.2800, 3.6000, 3.6000) | world origin mm (-67.3000, -103.0000, 10.0000) | bounds mm (-72.0800, -104.8000, 8.2000) → (-63.8000, -101.2000, 11.8000) | scale (1.0000, 1.0000, 1.0000) | mass g -1.0 | voltage V -1.0 | type Purchased socket screw
077. `Roller_Bearing_Right` | mesh `Roller_Bearing_Right_Mesh` | world dimensions mm (4.0000, 10.0000, 10.0000) | world origin mm (66.0000, -111.0000, 10.0000) | bounds mm (64.0000, -116.0000, 5.0000) → (68.0000, -106.0000, 15.0000) | scale (1.0000, 1.0000, 1.0000) | mass g -1.0 | voltage V -1.0 | type Purchased 623 bearing 3 x 10 x 4
078. `Bearing_Retainer_Right` | mesh `Bearing_Retainer_Right_Mesh` | world dimensions mm (1.8000, 22.0000, 16.0000) | world origin mm (68.9000, -111.0000, 10.0000) | bounds mm (68.0000, -122.0000, 2.0000) → (69.8000, -100.0000, 18.0000) | scale (1.0000, 1.0000, 1.0000) | mass g -1.0 | voltage V -1.0 | type Printed PETG part
079. `Bearing_Screw_Right-119` | mesh `Bearing_Screw_Right-119_Mesh` | world dimensions mm (8.2800, 3.6000, 3.6000) | world origin mm (67.3000, -119.0000, 10.0000) | bounds mm (63.8000, -120.8000, 8.2000) → (72.0800, -117.2000, 11.8000) | scale (1.0000, 1.0000, 1.0000) | mass g -1.0 | voltage V -1.0 | type Purchased socket screw
080. `Bearing_Screw_Right-103` | mesh `Bearing_Screw_Right-103_Mesh` | world dimensions mm (8.2800, 3.6000, 3.6000) | world origin mm (67.3000, -103.0000, 10.0000) | bounds mm (63.8000, -104.8000, 8.2000) → (72.0800, -101.2000, 11.8000) | scale (1.0000, 1.0000, 1.0000) | mass g -1.0 | voltage V -1.0 | type Purchased socket screw
081. `Roller_Core_SetScrew_-57` | mesh `Roller_Core_SetScrew_-57_Mesh` | world dimensions mm (2.5000, 2.5000, 7.0000) | world origin mm (-57.0000, -111.0000, 14.0000) | bounds mm (-58.2500, -112.2500, 10.5000) → (-55.7500, -109.7500, 17.5000) | scale (1.0000, 1.0000, 1.0000) | mass g -1.0 | voltage V -1.0 | type Purchased socket screw
082. `Roller_Core_SetScrew_57` | mesh `Roller_Core_SetScrew_57_Mesh` | world dimensions mm (2.5000, 2.5000, 7.0000) | world origin mm (57.0000, -111.0000, 14.0000) | bounds mm (55.7500, -112.2500, 10.5000) → (58.2500, -109.7500, 17.5000) | scale (1.0000, 1.0000, 1.0000) | mass g -1.0 | voltage V -1.0 | type Purchased socket screw
083. `Wiper_Motor_N20` | mesh `Wiper_Motor_N20_Mesh` | world dimensions mm (26.0000, 12.0000, 10.0000) | world origin mm (100.0000, -111.0000, 10.0000) | bounds mm (87.0000, -117.0000, 5.0000) → (113.0000, -105.0000, 15.0000) | scale (1.0000, 1.0000, 1.0000) | mass g 10.0 | voltage V 6.0 | type N20 geared wiper motor
084. `Wiper_Output_Shaft` | mesh `Wiper_Output_Shaft_Mesh` | world dimensions mm (10.0000, 3.0000, 3.0000) | world origin mm (82.0000, -111.0000, 10.0000) | bounds mm (77.0000, -112.5000, 8.5000) → (87.0000, -109.5000, 11.5000) | scale (1.0000, 1.0000, 1.0000) | mass g 0.0 | voltage V 6.0 | type N20 output shaft
085. `Roller_Shaft_Coupling` | mesh `Roller_Shaft_Coupling_Mesh` | world dimensions mm (14.0000, 11.0000, 11.0000) | world origin mm (77.0000, -111.0000, 10.0000) | bounds mm (70.0000, -116.5000, 4.5000) → (84.0000, -105.5000, 15.5000) | scale (1.0000, 1.0000, 1.0000) | mass g -1.0 | voltage V -1.0 | type Printed PETG part
086. `Coupling_SetScrew_72` | mesh `Coupling_SetScrew_72_Mesh` | world dimensions mm (2.5000, 2.5000, 5.0000) | world origin mm (72.0000, -111.0000, 13.0000) | bounds mm (70.7500, -112.2500, 10.5000) → (73.2500, -109.7500, 15.5000) | scale (1.0000, 1.0000, 1.0000) | mass g -1.0 | voltage V -1.0 | type Purchased socket screw
087. `Coupling_SetScrew_82` | mesh `Coupling_SetScrew_82_Mesh` | world dimensions mm (2.5000, 2.5000, 5.0000) | world origin mm (82.0000, -111.0000, 13.0000) | bounds mm (80.7500, -112.2500, 10.5000) → (83.2500, -109.7500, 15.5000) | scale (1.0000, 1.0000, 1.0000) | mass g -1.0 | voltage V -1.0 | type Purchased socket screw
088. `Wiper_Motor_Clamp` | mesh `Wiper_Motor_Clamp_Mesh` | world dimensions mm (22.0000, 28.0000, 3.0000) | world origin mm (99.0000, -111.0000, 16.9000) | bounds mm (88.0000, -125.0000, 15.4000) → (110.0000, -97.0000, 18.4000) | scale (1.0000, 1.0000, 1.0000) | mass g -1.0 | voltage V -1.0 | type Printed PETG part
089. `Wiper_Clamp_Pad` | mesh `Wiper_Clamp_Pad_Mesh` | world dimensions mm (20.0000, 12.0000, 0.4000) | world origin mm (99.0000, -111.0000, 15.2000) | bounds mm (89.0000, -117.0000, 15.0000) → (109.0000, -105.0000, 15.4000) | scale (1.0000, 1.0000, 1.0000) | mass g -1.0 | voltage V -1.0 | type Thin compliant clamp pad
090. `Wiper_Insert_-121` | mesh `Wiper_Insert_-121_Mesh` | world dimensions mm (3.6000, 3.6000, 4.0000) | world origin mm (99.0000, -121.0000, 13.3500) | bounds mm (97.2000, -122.8000, 11.3500) → (100.8000, -119.2000, 15.3500) | scale (1.0000, 1.0000, 1.0000) | mass g -1.0 | voltage V -1.0 | type Purchased M2.5 heat-set insert
091. `Wiper_Clamp_Screw_-121` | mesh `Wiper_Clamp_Screw_-121_Mesh` | world dimensions mm (4.5000, 4.5000, 9.6050) | world origin mm (99.0000, -121.0000, 14.4000) | bounds mm (96.7500, -123.2500, 10.4000) → (101.2500, -118.7500, 20.0050) | scale (1.0000, 1.0000, 1.0000) | mass g -1.0 | voltage V -1.0 | type Purchased socket screw
092. `Wiper_Insert_-101` | mesh `Wiper_Insert_-101_Mesh` | world dimensions mm (3.6000, 3.6000, 4.0000) | world origin mm (99.0000, -101.0000, 13.3500) | bounds mm (97.2000, -102.8000, 11.3500) → (100.8000, -99.2000, 15.3500) | scale (1.0000, 1.0000, 1.0000) | mass g -1.0 | voltage V -1.0 | type Purchased M2.5 heat-set insert
093. `Wiper_Clamp_Screw_-101` | mesh `Wiper_Clamp_Screw_-101_Mesh` | world dimensions mm (4.5000, 4.5000, 9.6050) | world origin mm (99.0000, -101.0000, 14.4000) | bounds mm (96.7500, -103.2500, 10.4000) → (101.2500, -98.7500, 20.0050) | scale (1.0000, 1.0000, 1.0000) | mass g -1.0 | voltage V -1.0 | type Purchased socket screw
094. `Battery_2S_LiPo_Tray` | mesh `Battery_2S_LiPo_Tray_Mesh` | world dimensions mm (70.0000, 35.0000, 5.5000) | world origin mm (0.0000, -57.0000, 10.0000) | bounds mm (-35.0000, -74.5000, 9.0000) → (35.0000, -39.5000, 14.5000) | scale (1.0000, 1.0000, 1.0000) | mass g -1.0 | voltage V -1.0 | type Printed PETG part
095. `Battery_2S_LiPo` | mesh `Battery_2S_LiPo_Mesh` | world dimensions mm (55.0000, 30.0000, 15.0000) | world origin mm (0.0000, -57.0000, 20.5000) | bounds mm (-27.5000, -72.0000, 13.0000) → (27.5000, -42.0000, 28.0000) | scale (1.0000, 1.0000, 1.0000) | mass g 40.0 | voltage V 7.4 | type Electronics module envelope
096. `Battery_2S_LiPo_Retaining_Strap` | mesh `Battery_2S_LiPo_Retaining_Strap_Mesh` | world dimensions mm (62.2000, 3.8000, 19.4000) | world origin mm (0.0000, -49.5000, 18.9000) | bounds mm (-31.1000, -51.4000, 9.2000) → (31.1000, -47.6000, 28.6000) | scale (1.0000, 1.0000, 1.0000) | mass g -1.0 | voltage V -1.0 | type Thin hook-and-loop retaining strap
097. `Battery_2S_LiPo_Insert_-31` | mesh `Battery_2S_LiPo_Insert_-31_Mesh` | world dimensions mm (3.6000, 3.6000, 4.0000) | world origin mm (-31.0000, -57.0000, 6.9000) | bounds mm (-32.8000, -58.8000, 4.9000) → (-29.2000, -55.2000, 8.9000) | scale (1.0000, 1.0000, 1.0000) | mass g -1.0 | voltage V -1.0 | type Purchased M2.5 heat-set insert
098. `Battery_2S_LiPo_Tray_Screw_-31` | mesh `Battery_2S_LiPo_Tray_Screw_-31_Mesh` | world dimensions mm (4.5000, 4.5000, 7.6050) | world origin mm (-31.0000, -57.0000, 8.0000) | bounds mm (-33.2500, -59.2500, 5.0000) → (-28.7500, -54.7500, 12.6050) | scale (1.0000, 1.0000, 1.0000) | mass g -1.0 | voltage V -1.0 | type Purchased socket screw
099. `Battery_2S_LiPo_Insert_31` | mesh `Battery_2S_LiPo_Insert_31_Mesh` | world dimensions mm (3.6000, 3.6000, 4.0000) | world origin mm (31.0000, -57.0000, 6.9000) | bounds mm (29.2000, -58.8000, 4.9000) → (32.8000, -55.2000, 8.9000) | scale (1.0000, 1.0000, 1.0000) | mass g -1.0 | voltage V -1.0 | type Purchased M2.5 heat-set insert
100. `Battery_2S_LiPo_Tray_Screw_31` | mesh `Battery_2S_LiPo_Tray_Screw_31_Mesh` | world dimensions mm (4.5000, 4.5000, 7.6050) | world origin mm (31.0000, -57.0000, 8.0000) | bounds mm (28.7500, -59.2500, 5.0000) → (33.2500, -54.7500, 12.6050) | scale (1.0000, 1.0000, 1.0000) | mass g -1.0 | voltage V -1.0 | type Purchased socket screw
101. `ESP32_S3_Tray` | mesh `ESP32_S3_Tray_Mesh` | world dimensions mm (68.0000, 33.0000, 5.5000) | world origin mm (0.0000, 58.0000, 10.0000) | bounds mm (-34.0000, 41.5000, 9.0000) → (34.0000, 74.5000, 14.5000) | scale (1.0000, 1.0000, 1.0000) | mass g -1.0 | voltage V -1.0 | type Printed PETG part
102. `ESP32_S3` | mesh `ESP32_S3_Mesh` | world dimensions mm (53.0000, 28.0000, 12.0000) | world origin mm (0.0000, 58.0000, 19.0000) | bounds mm (-26.5000, 44.0000, 13.0000) → (26.5000, 72.0000, 25.0000) | scale (1.0000, 1.0000, 1.0000) | mass g 10.0 | voltage V 3.3 | type Electronics module envelope
103. `ESP32_S3_Retaining_Strap` | mesh `ESP32_S3_Retaining_Strap_Mesh` | world dimensions mm (60.2000, 3.8000, 16.4000) | world origin mm (0.0000, 65.0000, 17.4000) | bounds mm (-30.1000, 63.1000, 9.2000) → (30.1000, 66.9000, 25.6000) | scale (1.0000, 1.0000, 1.0000) | mass g -1.0 | voltage V -1.0 | type Thin hook-and-loop retaining strap
104. `ESP32_S3_Insert_-30` | mesh `ESP32_S3_Insert_-30_Mesh` | world dimensions mm (3.6000, 3.6000, 4.0000) | world origin mm (-30.0000, 58.0000, 6.9000) | bounds mm (-31.8000, 56.2000, 4.9000) → (-28.2000, 59.8000, 8.9000) | scale (1.0000, 1.0000, 1.0000) | mass g -1.0 | voltage V -1.0 | type Purchased M2.5 heat-set insert
105. `ESP32_S3_Tray_Screw_-30` | mesh `ESP32_S3_Tray_Screw_-30_Mesh` | world dimensions mm (4.5000, 4.5000, 7.6050) | world origin mm (-30.0000, 58.0000, 8.0000) | bounds mm (-32.2500, 55.7500, 5.0000) → (-27.7500, 60.2500, 12.6050) | scale (1.0000, 1.0000, 1.0000) | mass g -1.0 | voltage V -1.0 | type Purchased socket screw
106. `ESP32_S3_Insert_30` | mesh `ESP32_S3_Insert_30_Mesh` | world dimensions mm (3.6000, 3.6000, 4.0000) | world origin mm (30.0000, 58.0000, 6.9000) | bounds mm (28.2000, 56.2000, 4.9000) → (31.8000, 59.8000, 8.9000) | scale (1.0000, 1.0000, 1.0000) | mass g -1.0 | voltage V -1.0 | type Purchased M2.5 heat-set insert
107. `ESP32_S3_Tray_Screw_30` | mesh `ESP32_S3_Tray_Screw_30_Mesh` | world dimensions mm (4.5000, 4.5000, 7.6050) | world origin mm (30.0000, 58.0000, 8.0000) | bounds mm (27.7500, 55.7500, 5.0000) → (32.2500, 60.2500, 12.6050) | scale (1.0000, 1.0000, 1.0000) | mass g -1.0 | voltage V -1.0 | type Purchased socket screw
108. `BLHeli_ESC_Tray` | mesh `BLHeli_ESC_Tray_Mesh` | world dimensions mm (17.0000, 30.0000, 5.5000) | world origin mm (55.0000, -18.0000, 10.0000) | bounds mm (46.5000, -33.0000, 9.0000) → (63.5000, -3.0000, 14.5000) | scale (1.0000, 1.0000, 1.0000) | mass g -1.0 | voltage V -1.0 | type Printed PETG part
109. `BLHeli_ESC` | mesh `BLHeli_ESC_Mesh` | world dimensions mm (12.0000, 25.0000, 5.0000) | world origin mm (55.0000, -18.0000, 15.5000) | bounds mm (49.0000, -30.5000, 13.0000) → (61.0000, -5.5000, 18.0000) | scale (1.0000, 1.0000, 1.0000) | mass g 10.0 | voltage V 7.4 | type Electronics module envelope
110. `BLHeli_ESC_Retaining_Strap` | mesh `BLHeli_ESC_Retaining_Strap_Mesh` | world dimensions mm (19.2000, 3.8000, 9.4000) | world origin mm (55.0000, -11.7500, 13.9000) | bounds mm (45.4000, -13.6500, 9.2000) → (64.6000, -9.8500, 18.6000) | scale (1.0000, 1.0000, 1.0000) | mass g -1.0 | voltage V -1.0 | type Thin hook-and-loop retaining strap
111. `BLHeli_ESC_Insert_58` | mesh `BLHeli_ESC_Insert_58_Mesh` | world dimensions mm (3.6000, 3.6000, 4.0000) | world origin mm (58.0000, -18.0000, 6.9000) | bounds mm (56.2000, -19.8000, 4.9000) → (59.8000, -16.2000, 8.9000) | scale (1.0000, 1.0000, 1.0000) | mass g -1.0 | voltage V -1.0 | type Purchased M2.5 heat-set insert
112. `BLHeli_ESC_Tray_Screw_58` | mesh `BLHeli_ESC_Tray_Screw_58_Mesh` | world dimensions mm (4.5000, 4.5000, 7.6050) | world origin mm (58.0000, -18.0000, 8.0000) | bounds mm (55.7500, -20.2500, 5.0000) → (60.2500, -15.7500, 12.6050) | scale (1.0000, 1.0000, 1.0000) | mass g -1.0 | voltage V -1.0 | type Purchased socket screw
113. `TB6612FNG_Tray` | mesh `TB6612FNG_Tray_Mesh` | world dimensions mm (25.0000, 25.0000, 5.5000) | world origin mm (53.0000, 21.0000, 10.0000) | bounds mm (40.5000, 8.5000, 9.0000) → (65.5000, 33.5000, 14.5000) | scale (1.0000, 1.0000, 1.0000) | mass g -1.0 | voltage V -1.0 | type Printed PETG part
114. `TB6612FNG` | mesh `TB6612FNG_Mesh` | world dimensions mm (20.0000, 20.0000, 5.0000) | world origin mm (53.0000, 21.0000, 15.5000) | bounds mm (43.0000, 11.0000, 13.0000) → (63.0000, 31.0000, 18.0000) | scale (1.0000, 1.0000, 1.0000) | mass g 5.0 | voltage V 7.4 | type Electronics module envelope
115. `TB6612FNG_Retaining_Strap` | mesh `TB6612FNG_Retaining_Strap_Mesh` | world dimensions mm (27.2000, 3.8000, 9.4000) | world origin mm (53.0000, 26.0000, 13.9000) | bounds mm (39.4000, 24.1000, 9.2000) → (66.6000, 27.9000, 18.6000) | scale (1.0000, 1.0000, 1.0000) | mass g -1.0 | voltage V -1.0 | type Thin hook-and-loop retaining strap
116. `TB6612FNG_Insert_58` | mesh `TB6612FNG_Insert_58_Mesh` | world dimensions mm (3.6000, 3.6000, 4.0000) | world origin mm (58.0000, 21.0000, 6.9000) | bounds mm (56.2000, 19.2000, 4.9000) → (59.8000, 22.8000, 8.9000) | scale (1.0000, 1.0000, 1.0000) | mass g -1.0 | voltage V -1.0 | type Purchased M2.5 heat-set insert
117. `TB6612FNG_Tray_Screw_58` | mesh `TB6612FNG_Tray_Screw_58_Mesh` | world dimensions mm (4.5000, 4.5000, 7.6050) | world origin mm (58.0000, 21.0000, 8.0000) | bounds mm (55.7500, 18.7500, 5.0000) → (60.2500, 23.2500, 12.6050) | scale (1.0000, 1.0000, 1.0000) | mass g -1.0 | voltage V -1.0 | type Purchased socket screw
118. `D4184_MOSFET_Tray` | mesh `D4184_MOSFET_Tray_Mesh` | world dimensions mm (23.0000, 39.0000, 5.5000) | world origin mm (-52.0000, -12.0000, 10.0000) | bounds mm (-64.0000, -31.5000, 9.0000) → (-41.0000, 7.5000, 14.5000) | scale (1.0000, 1.0000, 1.0000) | mass g -1.0 | voltage V -1.0 | type Printed PETG part
119. `D4184_MOSFET` | mesh `D4184_MOSFET_Mesh` | world dimensions mm (17.0000, 34.0000, 12.0000) | world origin mm (-52.0000, -12.0000, 19.0000) | bounds mm (-60.5000, -29.0000, 13.0000) → (-43.5000, 5.0000, 25.0000) | scale (1.0000, 1.0000, 1.0000) | mass g 5.0 | voltage V 7.4 | type Electronics module envelope
120. `D4184_MOSFET_Retaining_Strap` | mesh `D4184_MOSFET_Retaining_Strap_Mesh` | world dimensions mm (24.2000, 3.8000, 16.4000) | world origin mm (-52.0000, -3.5000, 17.4000) | bounds mm (-64.1000, -5.4000, 9.2000) → (-39.9000, -1.6000, 25.6000) | scale (1.0000, 1.0000, 1.0000) | mass g -1.0 | voltage V -1.0 | type Thin hook-and-loop retaining strap
121. `D4184_MOSFET_Insert_-60` | mesh `D4184_MOSFET_Insert_-60_Mesh` | world dimensions mm (3.6000, 3.6000, 4.0000) | world origin mm (-60.0000, -12.0000, 6.9000) | bounds mm (-61.8000, -13.8000, 4.9000) → (-58.2000, -10.2000, 8.9000) | scale (1.0000, 1.0000, 1.0000) | mass g -1.0 | voltage V -1.0 | type Purchased M2.5 heat-set insert
122. `D4184_MOSFET_Tray_Screw_-60` | mesh `D4184_MOSFET_Tray_Screw_-60_Mesh` | world dimensions mm (4.5000, 4.5000, 7.6050) | world origin mm (-60.0000, -12.0000, 8.0000) | bounds mm (-62.2500, -14.2500, 5.0000) → (-57.7500, -9.7500, 12.6050) | scale (1.0000, 1.0000, 1.0000) | mass g -1.0 | voltage V -1.0 | type Purchased socket screw
123. `TCRT5000_PCB_Left_Front` | mesh `TCRT5000_PCB_Left_Front_Mesh` | world dimensions mm (32.0000, 14.0000, 1.6000) | world origin mm (-43.0000, 87.0000, 10.3000) | bounds mm (-59.0000, 80.0000, 9.5000) → (-27.0000, 94.0000, 11.1000) | scale (1.0000, 1.0000, 1.0000) | mass g 3.25 | voltage V 3.3 | type TCRT5000 breakout PCB envelope
124. `TCRT5000_Optical_Left_Front` | mesh `TCRT5000_Optical_Left_Front_Mesh` | world dimensions mm (10.2000, 5.8000, 7.0000) | world origin mm (-53.0000, 87.0000, 6.0000) | bounds mm (-58.1000, 84.1000, 2.5000) → (-47.9000, 89.9000, 9.5000) | scale (1.0000, 1.0000, 1.0000) | mass g 0.5 | voltage V 3.3 | type Vishay TCRT5000 optical package
125. `IR_Lens_Left_Front-2.5` | mesh `IR_Lens_Left_Front-2.5_Mesh` | world dimensions mm (3.5000, 3.5000, 0.3000) | world origin mm (-55.5000, 87.0000, 2.6500) | bounds mm (-57.2500, 85.2500, 2.5000) → (-53.7500, 88.7500, 2.8000) | scale (1.0000, 1.0000, 1.0000) | mass g 0.0 | voltage V -1.0 | type Optical face
126. `IR_Lens_Left_Front2.5` | mesh `IR_Lens_Left_Front2.5_Mesh` | world dimensions mm (3.5000, 3.5000, 0.3000) | world origin mm (-50.5000, 87.0000, 2.6500) | bounds mm (-52.2500, 85.2500, 2.5000) → (-48.7500, 88.7500, 2.8000) | scale (1.0000, 1.0000, 1.0000) | mass g 0.0 | voltage V -1.0 | type Optical face
127. `IR_Trim_Pot_Left_Front` | mesh `IR_Trim_Pot_Left_Front_Mesh` | world dimensions mm (5.0000, 5.0000, 5.0000) | world origin mm (-35.0000, 85.0000, 13.6000) | bounds mm (-37.5000, 82.5000, 11.1000) → (-32.5000, 87.5000, 16.1000) | scale (1.0000, 1.0000, 1.0000) | mass g 0.0 | voltage V 3.3 | type Module adjustment potentiometer
128. `Sensor_Cartridge_Left_Front` | mesh `Sensor_Cartridge_Left_Front_Mesh` | world dimensions mm (45.0000, 18.0000, 5.0000) | world origin mm (-43.0000, 87.0000, 8.0000) | bounds mm (-65.5000, 78.0000, 6.5000) → (-20.5000, 96.0000, 11.5000) | scale (1.0000, 1.0000, 1.0000) | mass g -1.0 | voltage V -1.0 | type Printed PETG part
129. `Sensor_Height_Shim_Left_Front` | mesh `Sensor_Height_Shim_Left_Front_Mesh` | world dimensions mm (45.0000, 18.0000, 0.5000) | world origin mm (-43.0000, 87.0000, 6.2500) | bounds mm (-65.5000, 78.0000, 6.0000) → (-20.5000, 96.0000, 6.5000) | scale (1.0000, 1.0000, 1.0000) | mass g -1.0 | voltage V -1.0 | type Printed PETG part
130. `Sensor_Edge_Clamp_Left_Front` | mesh `Sensor_Edge_Clamp_Left_Front_Mesh` | world dimensions mm (46.0000, 18.0000, 2.0000) | world origin mm (-43.0000, 93.0000, 12.5000) | bounds mm (-66.0000, 78.0000, 11.5000) → (-20.0000, 96.0000, 13.5000) | scale (1.0000, 1.0000, 1.0000) | mass g -1.0 | voltage V -1.0 | type Printed PETG part
131. `Sensor_Clamp_Pad_Left_Front` | mesh `Sensor_Clamp_Pad_Left_Front_Mesh` | world dimensions mm (30.0000, 2.0000, 0.4000) | world origin mm (-43.0000, 93.0000, 11.3000) | bounds mm (-58.0000, 92.0000, 11.1000) → (-28.0000, 94.0000, 11.5000) | scale (1.0000, 1.0000, 1.0000) | mass g -1.0 | voltage V -1.0 | type Compliant PCB edge pad
132. `Sensor_Insert_Left_Front-62` | mesh `Sensor_Insert_Left_Front-62_Mesh` | world dimensions mm (3.6000, 3.6000, 3.0000) | world origin mm (-62.0000, 87.0000, 4.5000) | bounds mm (-63.8000, 85.2000, 3.0000) → (-60.2000, 88.8000, 6.0000) | scale (1.0000, 1.0000, 1.0000) | mass g -1.0 | voltage V -1.0 | type Purchased M2.5 heat-set insert
133. `Sensor_Screw_Left_Front-62` | mesh `Sensor_Screw_Left_Front-62_Mesh` | world dimensions mm (4.5000, 4.5000, 11.6050) | world origin mm (-62.0000, 87.0000, 8.5000) | bounds mm (-64.2500, 84.7500, 3.5000) → (-59.7500, 89.2500, 15.1050) | scale (1.0000, 1.0000, 1.0000) | mass g -1.0 | voltage V -1.0 | type Purchased socket screw
134. `Sensor_Insert_Left_Front-24` | mesh `Sensor_Insert_Left_Front-24_Mesh` | world dimensions mm (3.6000, 3.6000, 3.0000) | world origin mm (-24.0000, 87.0000, 4.5000) | bounds mm (-25.8000, 85.2000, 3.0000) → (-22.2000, 88.8000, 6.0000) | scale (1.0000, 1.0000, 1.0000) | mass g -1.0 | voltage V -1.0 | type Purchased M2.5 heat-set insert
135. `Sensor_Screw_Left_Front-24` | mesh `Sensor_Screw_Left_Front-24_Mesh` | world dimensions mm (4.5000, 4.5000, 11.6050) | world origin mm (-24.0000, 87.0000, 8.5000) | bounds mm (-26.2500, 84.7500, 3.5000) → (-21.7500, 89.2500, 15.1050) | scale (1.0000, 1.0000, 1.0000) | mass g -1.0 | voltage V -1.0 | type Purchased socket screw
136. `TCRT5000_PCB_Left_Rear` | mesh `TCRT5000_PCB_Left_Rear_Mesh` | world dimensions mm (32.0000, 14.0000, 1.6000) | world origin mm (-43.0000, -87.0000, 10.3000) | bounds mm (-59.0000, -94.0000, 9.5000) → (-27.0000, -80.0000, 11.1000) | scale (1.0000, 1.0000, 1.0000) | mass g 3.25 | voltage V 3.3 | type TCRT5000 breakout PCB envelope
137. `TCRT5000_Optical_Left_Rear` | mesh `TCRT5000_Optical_Left_Rear_Mesh` | world dimensions mm (10.2000, 5.8000, 7.0000) | world origin mm (-53.0000, -87.0000, 6.0000) | bounds mm (-58.1000, -89.9000, 2.5000) → (-47.9000, -84.1000, 9.5000) | scale (1.0000, 1.0000, 1.0000) | mass g 0.5 | voltage V 3.3 | type Vishay TCRT5000 optical package
138. `IR_Lens_Left_Rear-2.5` | mesh `IR_Lens_Left_Rear-2.5_Mesh` | world dimensions mm (3.5000, 3.5000, 0.3000) | world origin mm (-55.5000, -87.0000, 2.6500) | bounds mm (-57.2500, -88.7500, 2.5000) → (-53.7500, -85.2500, 2.8000) | scale (1.0000, 1.0000, 1.0000) | mass g 0.0 | voltage V -1.0 | type Optical face
139. `IR_Lens_Left_Rear2.5` | mesh `IR_Lens_Left_Rear2.5_Mesh` | world dimensions mm (3.5000, 3.5000, 0.3000) | world origin mm (-50.5000, -87.0000, 2.6500) | bounds mm (-52.2500, -88.7500, 2.5000) → (-48.7500, -85.2500, 2.8000) | scale (1.0000, 1.0000, 1.0000) | mass g 0.0 | voltage V -1.0 | type Optical face
140. `IR_Trim_Pot_Left_Rear` | mesh `IR_Trim_Pot_Left_Rear_Mesh` | world dimensions mm (5.0000, 5.0000, 5.0000) | world origin mm (-35.0000, -89.0000, 13.6000) | bounds mm (-37.5000, -91.5000, 11.1000) → (-32.5000, -86.5000, 16.1000) | scale (1.0000, 1.0000, 1.0000) | mass g 0.0 | voltage V 3.3 | type Module adjustment potentiometer
141. `Sensor_Cartridge_Left_Rear` | mesh `Sensor_Cartridge_Left_Rear_Mesh` | world dimensions mm (45.0000, 18.0000, 5.0000) | world origin mm (-43.0000, -87.0000, 8.0000) | bounds mm (-65.5000, -96.0000, 6.5000) → (-20.5000, -78.0000, 11.5000) | scale (1.0000, 1.0000, 1.0000) | mass g -1.0 | voltage V -1.0 | type Printed PETG part
142. `Sensor_Height_Shim_Left_Rear` | mesh `Sensor_Height_Shim_Left_Rear_Mesh` | world dimensions mm (45.0000, 18.0000, 0.5000) | world origin mm (-43.0000, -87.0000, 6.2500) | bounds mm (-65.5000, -96.0000, 6.0000) → (-20.5000, -78.0000, 6.5000) | scale (1.0000, 1.0000, 1.0000) | mass g -1.0 | voltage V -1.0 | type Printed PETG part
143. `Sensor_Edge_Clamp_Left_Rear` | mesh `Sensor_Edge_Clamp_Left_Rear_Mesh` | world dimensions mm (46.0000, 18.0000, 2.0000) | world origin mm (-43.0000, -81.0000, 12.5000) | bounds mm (-66.0000, -96.0000, 11.5000) → (-20.0000, -78.0000, 13.5000) | scale (1.0000, 1.0000, 1.0000) | mass g -1.0 | voltage V -1.0 | type Printed PETG part
144. `Sensor_Clamp_Pad_Left_Rear` | mesh `Sensor_Clamp_Pad_Left_Rear_Mesh` | world dimensions mm (30.0000, 2.0000, 0.4000) | world origin mm (-43.0000, -81.0000, 11.3000) | bounds mm (-58.0000, -82.0000, 11.1000) → (-28.0000, -80.0000, 11.5000) | scale (1.0000, 1.0000, 1.0000) | mass g -1.0 | voltage V -1.0 | type Compliant PCB edge pad
145. `Sensor_Insert_Left_Rear-62` | mesh `Sensor_Insert_Left_Rear-62_Mesh` | world dimensions mm (3.6000, 3.6000, 3.0000) | world origin mm (-62.0000, -87.0000, 4.5000) | bounds mm (-63.8000, -88.8000, 3.0000) → (-60.2000, -85.2000, 6.0000) | scale (1.0000, 1.0000, 1.0000) | mass g -1.0 | voltage V -1.0 | type Purchased M2.5 heat-set insert
146. `Sensor_Screw_Left_Rear-62` | mesh `Sensor_Screw_Left_Rear-62_Mesh` | world dimensions mm (4.5000, 4.5000, 11.6050) | world origin mm (-62.0000, -87.0000, 8.5000) | bounds mm (-64.2500, -89.2500, 3.5000) → (-59.7500, -84.7500, 15.1050) | scale (1.0000, 1.0000, 1.0000) | mass g -1.0 | voltage V -1.0 | type Purchased socket screw
147. `Sensor_Insert_Left_Rear-24` | mesh `Sensor_Insert_Left_Rear-24_Mesh` | world dimensions mm (3.6000, 3.6000, 3.0000) | world origin mm (-24.0000, -87.0000, 4.5000) | bounds mm (-25.8000, -88.8000, 3.0000) → (-22.2000, -85.2000, 6.0000) | scale (1.0000, 1.0000, 1.0000) | mass g -1.0 | voltage V -1.0 | type Purchased M2.5 heat-set insert
148. `Sensor_Screw_Left_Rear-24` | mesh `Sensor_Screw_Left_Rear-24_Mesh` | world dimensions mm (4.5000, 4.5000, 11.6050) | world origin mm (-24.0000, -87.0000, 8.5000) | bounds mm (-26.2500, -89.2500, 3.5000) → (-21.7500, -84.7500, 15.1050) | scale (1.0000, 1.0000, 1.0000) | mass g -1.0 | voltage V -1.0 | type Purchased socket screw
149. `TCRT5000_PCB_Right_Front` | mesh `TCRT5000_PCB_Right_Front_Mesh` | world dimensions mm (32.0000, 14.0000, 1.6000) | world origin mm (43.0000, 87.0000, 10.3000) | bounds mm (27.0000, 80.0000, 9.5000) → (59.0000, 94.0000, 11.1000) | scale (1.0000, 1.0000, 1.0000) | mass g 3.25 | voltage V 3.3 | type TCRT5000 breakout PCB envelope
150. `TCRT5000_Optical_Right_Front` | mesh `TCRT5000_Optical_Right_Front_Mesh` | world dimensions mm (10.2000, 5.8000, 7.0000) | world origin mm (53.0000, 87.0000, 6.0000) | bounds mm (47.9000, 84.1000, 2.5000) → (58.1000, 89.9000, 9.5000) | scale (1.0000, 1.0000, 1.0000) | mass g 0.5 | voltage V 3.3 | type Vishay TCRT5000 optical package
151. `IR_Lens_Right_Front-2.5` | mesh `IR_Lens_Right_Front-2.5_Mesh` | world dimensions mm (3.5000, 3.5000, 0.3000) | world origin mm (50.5000, 87.0000, 2.6500) | bounds mm (48.7500, 85.2500, 2.5000) → (52.2500, 88.7500, 2.8000) | scale (1.0000, 1.0000, 1.0000) | mass g 0.0 | voltage V -1.0 | type Optical face
152. `IR_Lens_Right_Front2.5` | mesh `IR_Lens_Right_Front2.5_Mesh` | world dimensions mm (3.5000, 3.5000, 0.3000) | world origin mm (55.5000, 87.0000, 2.6500) | bounds mm (53.7500, 85.2500, 2.5000) → (57.2500, 88.7500, 2.8000) | scale (1.0000, 1.0000, 1.0000) | mass g 0.0 | voltage V -1.0 | type Optical face
153. `IR_Trim_Pot_Right_Front` | mesh `IR_Trim_Pot_Right_Front_Mesh` | world dimensions mm (5.0000, 5.0000, 5.0000) | world origin mm (35.0000, 85.0000, 13.6000) | bounds mm (32.5000, 82.5000, 11.1000) → (37.5000, 87.5000, 16.1000) | scale (1.0000, 1.0000, 1.0000) | mass g 0.0 | voltage V 3.3 | type Module adjustment potentiometer
154. `Sensor_Cartridge_Right_Front` | mesh `Sensor_Cartridge_Right_Front_Mesh` | world dimensions mm (45.0000, 18.0000, 5.0000) | world origin mm (43.0000, 87.0000, 8.0000) | bounds mm (20.5000, 78.0000, 6.5000) → (65.5000, 96.0000, 11.5000) | scale (1.0000, 1.0000, 1.0000) | mass g -1.0 | voltage V -1.0 | type Printed PETG part
155. `Sensor_Height_Shim_Right_Front` | mesh `Sensor_Height_Shim_Right_Front_Mesh` | world dimensions mm (45.0000, 18.0000, 0.5000) | world origin mm (43.0000, 87.0000, 6.2500) | bounds mm (20.5000, 78.0000, 6.0000) → (65.5000, 96.0000, 6.5000) | scale (1.0000, 1.0000, 1.0000) | mass g -1.0 | voltage V -1.0 | type Printed PETG part
156. `Sensor_Edge_Clamp_Right_Front` | mesh `Sensor_Edge_Clamp_Right_Front_Mesh` | world dimensions mm (46.0000, 18.0000, 2.0000) | world origin mm (43.0000, 93.0000, 12.5000) | bounds mm (20.0000, 78.0000, 11.5000) → (66.0000, 96.0000, 13.5000) | scale (1.0000, 1.0000, 1.0000) | mass g -1.0 | voltage V -1.0 | type Printed PETG part
157. `Sensor_Clamp_Pad_Right_Front` | mesh `Sensor_Clamp_Pad_Right_Front_Mesh` | world dimensions mm (30.0000, 2.0000, 0.4000) | world origin mm (43.0000, 93.0000, 11.3000) | bounds mm (28.0000, 92.0000, 11.1000) → (58.0000, 94.0000, 11.5000) | scale (1.0000, 1.0000, 1.0000) | mass g -1.0 | voltage V -1.0 | type Compliant PCB edge pad
158. `Sensor_Insert_Right_Front24` | mesh `Sensor_Insert_Right_Front24_Mesh` | world dimensions mm (3.6000, 3.6000, 3.0000) | world origin mm (24.0000, 87.0000, 4.5000) | bounds mm (22.2000, 85.2000, 3.0000) → (25.8000, 88.8000, 6.0000) | scale (1.0000, 1.0000, 1.0000) | mass g -1.0 | voltage V -1.0 | type Purchased M2.5 heat-set insert
159. `Sensor_Screw_Right_Front24` | mesh `Sensor_Screw_Right_Front24_Mesh` | world dimensions mm (4.5000, 4.5000, 11.6050) | world origin mm (24.0000, 87.0000, 8.5000) | bounds mm (21.7500, 84.7500, 3.5000) → (26.2500, 89.2500, 15.1050) | scale (1.0000, 1.0000, 1.0000) | mass g -1.0 | voltage V -1.0 | type Purchased socket screw
160. `Sensor_Insert_Right_Front62` | mesh `Sensor_Insert_Right_Front62_Mesh` | world dimensions mm (3.6000, 3.6000, 3.0000) | world origin mm (62.0000, 87.0000, 4.5000) | bounds mm (60.2000, 85.2000, 3.0000) → (63.8000, 88.8000, 6.0000) | scale (1.0000, 1.0000, 1.0000) | mass g -1.0 | voltage V -1.0 | type Purchased M2.5 heat-set insert
161. `Sensor_Screw_Right_Front62` | mesh `Sensor_Screw_Right_Front62_Mesh` | world dimensions mm (4.5000, 4.5000, 11.6050) | world origin mm (62.0000, 87.0000, 8.5000) | bounds mm (59.7500, 84.7500, 3.5000) → (64.2500, 89.2500, 15.1050) | scale (1.0000, 1.0000, 1.0000) | mass g -1.0 | voltage V -1.0 | type Purchased socket screw
162. `TCRT5000_PCB_Right_Rear` | mesh `TCRT5000_PCB_Right_Rear_Mesh` | world dimensions mm (32.0000, 14.0000, 1.6000) | world origin mm (43.0000, -87.0000, 10.3000) | bounds mm (27.0000, -94.0000, 9.5000) → (59.0000, -80.0000, 11.1000) | scale (1.0000, 1.0000, 1.0000) | mass g 3.25 | voltage V 3.3 | type TCRT5000 breakout PCB envelope
163. `TCRT5000_Optical_Right_Rear` | mesh `TCRT5000_Optical_Right_Rear_Mesh` | world dimensions mm (10.2000, 5.8000, 7.0000) | world origin mm (53.0000, -87.0000, 6.0000) | bounds mm (47.9000, -89.9000, 2.5000) → (58.1000, -84.1000, 9.5000) | scale (1.0000, 1.0000, 1.0000) | mass g 0.5 | voltage V 3.3 | type Vishay TCRT5000 optical package
164. `IR_Lens_Right_Rear-2.5` | mesh `IR_Lens_Right_Rear-2.5_Mesh` | world dimensions mm (3.5000, 3.5000, 0.3000) | world origin mm (50.5000, -87.0000, 2.6500) | bounds mm (48.7500, -88.7500, 2.5000) → (52.2500, -85.2500, 2.8000) | scale (1.0000, 1.0000, 1.0000) | mass g 0.0 | voltage V -1.0 | type Optical face
165. `IR_Lens_Right_Rear2.5` | mesh `IR_Lens_Right_Rear2.5_Mesh` | world dimensions mm (3.5000, 3.5000, 0.3000) | world origin mm (55.5000, -87.0000, 2.6500) | bounds mm (53.7500, -88.7500, 2.5000) → (57.2500, -85.2500, 2.8000) | scale (1.0000, 1.0000, 1.0000) | mass g 0.0 | voltage V -1.0 | type Optical face
166. `IR_Trim_Pot_Right_Rear` | mesh `IR_Trim_Pot_Right_Rear_Mesh` | world dimensions mm (5.0000, 5.0000, 5.0000) | world origin mm (35.0000, -89.0000, 13.6000) | bounds mm (32.5000, -91.5000, 11.1000) → (37.5000, -86.5000, 16.1000) | scale (1.0000, 1.0000, 1.0000) | mass g 0.0 | voltage V 3.3 | type Module adjustment potentiometer
167. `Sensor_Cartridge_Right_Rear` | mesh `Sensor_Cartridge_Right_Rear_Mesh` | world dimensions mm (45.0000, 18.0000, 5.0000) | world origin mm (43.0000, -87.0000, 8.0000) | bounds mm (20.5000, -96.0000, 6.5000) → (65.5000, -78.0000, 11.5000) | scale (1.0000, 1.0000, 1.0000) | mass g -1.0 | voltage V -1.0 | type Printed PETG part
168. `Sensor_Height_Shim_Right_Rear` | mesh `Sensor_Height_Shim_Right_Rear_Mesh` | world dimensions mm (45.0000, 18.0000, 0.5000) | world origin mm (43.0000, -87.0000, 6.2500) | bounds mm (20.5000, -96.0000, 6.0000) → (65.5000, -78.0000, 6.5000) | scale (1.0000, 1.0000, 1.0000) | mass g -1.0 | voltage V -1.0 | type Printed PETG part
169. `Sensor_Edge_Clamp_Right_Rear` | mesh `Sensor_Edge_Clamp_Right_Rear_Mesh` | world dimensions mm (46.0000, 18.0000, 2.0000) | world origin mm (43.0000, -81.0000, 12.5000) | bounds mm (20.0000, -96.0000, 11.5000) → (66.0000, -78.0000, 13.5000) | scale (1.0000, 1.0000, 1.0000) | mass g -1.0 | voltage V -1.0 | type Printed PETG part
170. `Sensor_Clamp_Pad_Right_Rear` | mesh `Sensor_Clamp_Pad_Right_Rear_Mesh` | world dimensions mm (30.0000, 2.0000, 0.4000) | world origin mm (43.0000, -81.0000, 11.3000) | bounds mm (28.0000, -82.0000, 11.1000) → (58.0000, -80.0000, 11.5000) | scale (1.0000, 1.0000, 1.0000) | mass g -1.0 | voltage V -1.0 | type Compliant PCB edge pad
171. `Sensor_Insert_Right_Rear24` | mesh `Sensor_Insert_Right_Rear24_Mesh` | world dimensions mm (3.6000, 3.6000, 3.0000) | world origin mm (24.0000, -87.0000, 4.5000) | bounds mm (22.2000, -88.8000, 3.0000) → (25.8000, -85.2000, 6.0000) | scale (1.0000, 1.0000, 1.0000) | mass g -1.0 | voltage V -1.0 | type Purchased M2.5 heat-set insert
172. `Sensor_Screw_Right_Rear24` | mesh `Sensor_Screw_Right_Rear24_Mesh` | world dimensions mm (4.5000, 4.5000, 11.6050) | world origin mm (24.0000, -87.0000, 8.5000) | bounds mm (21.7500, -89.2500, 3.5000) → (26.2500, -84.7500, 15.1050) | scale (1.0000, 1.0000, 1.0000) | mass g -1.0 | voltage V -1.0 | type Purchased socket screw
173. `Sensor_Insert_Right_Rear62` | mesh `Sensor_Insert_Right_Rear62_Mesh` | world dimensions mm (3.6000, 3.6000, 3.0000) | world origin mm (62.0000, -87.0000, 4.5000) | bounds mm (60.2000, -88.8000, 3.0000) → (63.8000, -85.2000, 6.0000) | scale (1.0000, 1.0000, 1.0000) | mass g -1.0 | voltage V -1.0 | type Purchased M2.5 heat-set insert
174. `Sensor_Screw_Right_Rear62` | mesh `Sensor_Screw_Right_Rear62_Mesh` | world dimensions mm (4.5000, 4.5000, 11.6050) | world origin mm (62.0000, -87.0000, 8.5000) | bounds mm (59.7500, -89.2500, 3.5000) → (64.2500, -84.7500, 15.1050) | scale (1.0000, 1.0000, 1.0000) | mass g -1.0 | voltage V -1.0 | type Purchased socket screw
175. `Charging_Contact_Block` | mesh `Charging_Contact_Block_Mesh` | world dimensions mm (48.0000, 8.0000, 7.0000) | world origin mm (0.0000, 96.0000, 9.5000) | bounds mm (-24.0000, 92.0000, 6.0000) → (24.0000, 100.0000, 13.0000) | scale (1.0000, 1.0000, 1.0000) | mass g -1.0 | voltage V -1.0 | type Printed PETG part
176. `Contact_Block_Screw_-9` | mesh `Contact_Block_Screw_-9_Mesh` | world dimensions mm (4.5000, 4.5000, 10.6050) | world origin mm (-9.0000, 95.0000, 8.5000) | bounds mm (-11.2500, 92.7500, 4.0000) → (-6.7500, 97.2500, 14.6050) | scale (1.0000, 1.0000, 1.0000) | mass g -1.0 | voltage V -1.0 | type Purchased socket screw
177. `Contact_Block_Screw_9` | mesh `Contact_Block_Screw_9_Mesh` | world dimensions mm (4.5000, 4.5000, 10.6050) | world origin mm (9.0000, 95.0000, 8.5000) | bounds mm (6.7500, 92.7500, 4.0000) → (11.2500, 97.2500, 14.6050) | scale (1.0000, 1.0000, 1.0000) | mass g -1.0 | voltage V -1.0 | type Purchased socket screw
178. `Charging_Plate_Left` | mesh `Charging_Plate_Left_Mesh` | world dimensions mm (5.0000, 0.6000, 4.0000) | world origin mm (-16.0000, 99.8000, 9.5000) | bounds mm (-18.5000, 99.5000, 7.5000) → (-13.5000, 100.1000, 11.5000) | scale (1.0000, 1.0000, 1.0000) | mass g 1.25 | voltage V -1.0 | type Copper charging plate
179. `Pogo_Pin_Left` | mesh `Pogo_Pin_Left_Mesh` | world dimensions mm (2.0000, 5.0000, 2.0000) | world origin mm (-16.0000, 101.6000, 9.5000) | bounds mm (-17.0000, 99.1000, 8.5000) → (-15.0000, 104.1000, 10.5000) | scale (1.0000, 1.0000, 1.0000) | mass g 1.25 | voltage V -1.0 | type Purchased spring contact
180. `Charging_Plate_Right` | mesh `Charging_Plate_Right_Mesh` | world dimensions mm (5.0000, 0.6000, 4.0000) | world origin mm (16.0000, 99.8000, 9.5000) | bounds mm (13.5000, 99.5000, 7.5000) → (18.5000, 100.1000, 11.5000) | scale (1.0000, 1.0000, 1.0000) | mass g 1.25 | voltage V -1.0 | type Copper charging plate
181. `Pogo_Pin_Right` | mesh `Pogo_Pin_Right_Mesh` | world dimensions mm (2.0000, 5.0000, 2.0000) | world origin mm (16.0000, 101.6000, 9.5000) | bounds mm (15.0000, 99.1000, 8.5000) → (17.0000, 104.1000, 10.5000) | scale (1.0000, 1.0000, 1.0000) | mass g 1.25 | voltage V -1.0 | type Purchased spring contact
182. `Sports_Car_Service_Cover` | mesh `Sports_Car_Service_Cover_Mesh` | world dimensions mm (149.0000, 196.0000, 56.0000) | world origin mm (0.0000, 0.0000, 0.0000) | bounds mm (-74.5000, -98.0000, 8.0000) → (74.5000, 98.0000, 64.0000) | scale (1.0000, 1.0000, 1.0000) | mass g -1.0 | voltage V -1.0 | type Printed PETG part
183. `Cover_Insert_-66_-29` | mesh `Cover_Insert_-66_-29_Mesh` | world dimensions mm (3.6000, 3.6000, 4.0000) | world origin mm (-66.0000, -29.0000, 6.1000) | bounds mm (-67.8000, -30.8000, 4.1000) → (-64.2000, -27.2000, 8.1000) | scale (1.0000, 1.0000, 1.0000) | mass g -1.0 | voltage V -1.0 | type Purchased M2.5 heat-set insert
184. `Cover_Screw_-66_-29` | mesh `Cover_Screw_-66_-29_Mesh` | world dimensions mm (4.5000, 4.5000, 8.6050) | world origin mm (-66.0000, -29.0000, 7.7000) | bounds mm (-68.2500, -31.2500, 4.2000) → (-63.7500, -26.7500, 12.8050) | scale (1.0000, 1.0000, 1.0000) | mass g -1.0 | voltage V -1.0 | type Purchased socket screw
185. `Cover_Insert_-66_29` | mesh `Cover_Insert_-66_29_Mesh` | world dimensions mm (3.6000, 3.6000, 4.0000) | world origin mm (-66.0000, 29.0000, 6.1000) | bounds mm (-67.8000, 27.2000, 4.1000) → (-64.2000, 30.8000, 8.1000) | scale (1.0000, 1.0000, 1.0000) | mass g -1.0 | voltage V -1.0 | type Purchased M2.5 heat-set insert
186. `Cover_Screw_-66_29` | mesh `Cover_Screw_-66_29_Mesh` | world dimensions mm (4.5000, 4.5000, 8.6050) | world origin mm (-66.0000, 29.0000, 7.7000) | bounds mm (-68.2500, 26.7500, 4.2000) → (-63.7500, 31.2500, 12.8050) | scale (1.0000, 1.0000, 1.0000) | mass g -1.0 | voltage V -1.0 | type Purchased socket screw
187. `Cover_Insert_66_-29` | mesh `Cover_Insert_66_-29_Mesh` | world dimensions mm (3.6000, 3.6000, 4.0000) | world origin mm (66.0000, -29.0000, 6.1000) | bounds mm (64.2000, -30.8000, 4.1000) → (67.8000, -27.2000, 8.1000) | scale (1.0000, 1.0000, 1.0000) | mass g -1.0 | voltage V -1.0 | type Purchased M2.5 heat-set insert
188. `Cover_Screw_66_-29` | mesh `Cover_Screw_66_-29_Mesh` | world dimensions mm (4.5000, 4.5000, 8.6050) | world origin mm (66.0000, -29.0000, 7.7000) | bounds mm (63.7500, -31.2500, 4.2000) → (68.2500, -26.7500, 12.8050) | scale (1.0000, 1.0000, 1.0000) | mass g -1.0 | voltage V -1.0 | type Purchased socket screw
189. `Cover_Insert_66_29` | mesh `Cover_Insert_66_29_Mesh` | world dimensions mm (3.6000, 3.6000, 4.0000) | world origin mm (66.0000, 29.0000, 6.1000) | bounds mm (64.2000, 27.2000, 4.1000) → (67.8000, 30.8000, 8.1000) | scale (1.0000, 1.0000, 1.0000) | mass g -1.0 | voltage V -1.0 | type Purchased M2.5 heat-set insert
190. `Cover_Screw_66_29` | mesh `Cover_Screw_66_29_Mesh` | world dimensions mm (4.5000, 4.5000, 8.6050) | world origin mm (66.0000, 29.0000, 7.7000) | bounds mm (63.7500, 26.7500, 4.2000) → (68.2500, 31.2500, 12.8050) | scale (1.0000, 1.0000, 1.0000) | mass g -1.0 | voltage V -1.0 | type Purchased socket screw
191. `Exhaust_Grille` | mesh `Exhaust_Grille_Mesh` | world dimensions mm (51.0000, 51.0000, 2.0000) | world origin mm (0.0000, 0.0000, 65.0000) | bounds mm (-25.5000, -25.5000, 64.0000) → (25.5000, 25.5000, 66.0000) | scale (1.0000, 1.0000, 1.0000) | mass g -1.0 | voltage V -1.0 | type Printed PETG part
192. `Racing_Stripe_-1_28` | mesh `Racing_Stripe_-1_28_Mesh` | world dimensions mm (5.0000, 67.0000, 40.8333) | world origin mm (0.0000, 0.0000, 0.0000) | bounds mm (-9.0000, 28.0000, 23.3267) → (-4.0000, 95.0000, 64.1600) | scale (1.0000, 1.0000, 1.0000) | mass g 0.0 | voltage V -1.0 | type Paint / vinyl graphic
193. `Racing_Stripe_-1_-95` | mesh `Racing_Stripe_-1_-95_Mesh` | world dimensions mm (5.0000, 67.0000, 38.6667) | world origin mm (0.0000, 0.0000, 0.0000) | bounds mm (-9.0000, -95.0000, 25.4933) → (-4.0000, -28.0000, 64.1600) | scale (1.0000, 1.0000, 1.0000) | mass g 0.0 | voltage V -1.0 | type Paint / vinyl graphic
194. `Headlight_Graphic_-1` | mesh `Headlight_Graphic_-1_Mesh` | world dimensions mm (16.0000, 5.0000, 1.9444) | world origin mm (0.0000, 0.0000, 0.0000) | bounds mm (-30.0000, 84.0000, 25.7000) → (-14.0000, 89.0000, 27.6444) | scale (1.0000, 1.0000, 1.0000) | mass g 0.0 | voltage V -1.0 | type Paint / vinyl graphic
195. `Racing_Stripe_1_28` | mesh `Racing_Stripe_1_28_Mesh` | world dimensions mm (5.0000, 67.0000, 40.8333) | world origin mm (0.0000, 0.0000, 0.0000) | bounds mm (4.0000, 28.0000, 23.3267) → (9.0000, 95.0000, 64.1600) | scale (1.0000, 1.0000, 1.0000) | mass g 0.0 | voltage V -1.0 | type Paint / vinyl graphic
196. `Racing_Stripe_1_-95` | mesh `Racing_Stripe_1_-95_Mesh` | world dimensions mm (5.0000, 67.0000, 38.6667) | world origin mm (0.0000, 0.0000, 0.0000) | bounds mm (4.0000, -95.0000, 25.4933) → (9.0000, -28.0000, 64.1600) | scale (1.0000, 1.0000, 1.0000) | mass g 0.0 | voltage V -1.0 | type Paint / vinyl graphic
197. `Headlight_Graphic_1` | mesh `Headlight_Graphic_1_Mesh` | world dimensions mm (16.0000, 5.0000, 1.9444) | world origin mm (0.0000, 0.0000, 0.0000) | bounds mm (14.0000, 84.0000, 25.7000) → (30.0000, 89.0000, 27.6444) | scale (1.0000, 1.0000, 1.0000) | mass g 0.0 | voltage V -1.0 | type Paint / vinyl graphic
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

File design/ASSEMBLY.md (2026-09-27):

# Assembly-oriented prototype — revision 2

This revision implements four drive motors per the user's latest decision. The hardware PDF remains the component-family reference. The 140 × 120 mm limit is removed. The source files and complete model from the first blockout are preserved in `archive/blockout_v1/`.

## Interfaces implemented

- One continuous chassis: base, wheel wells, blind insert pockets, sensor seats, rear roller forks and wiper-motor extension.
- Full-footprint 2 mm sponge, with central 56 mm vacuum aperture and wheel/sensor reliefs. It is no longer a perimeter-only ring.
- Chassis through-port, flange gasket, removable tapered adapter, EDF inlet gasket, split casing clamp and QX-Motor 30 mm six-blade EDF with QF1611.
- Four matching motor clamps, 3 mm nominal output shafts, aluminum wheel hubs and silicone tires on common axes.
- Rear microfiber sleeve on a printed core, 3 mm steel axle, two 623 bearings, bearing shoulders, bolted retainers and a separate motor coupling.
- Printed electronics trays with support rails and retention-strap provision; battery/boards no longer float over the chassis.
- Four chassis-mounted sensor cartridges, shims and PCB edge clamps. See `SENSOR_MOUNT.md`.
- Bolted front charging-contact block.
- Removable 2 mm sports-style shell, racing graphics, wheel arches and an open exhaust grille.

## Printed and purchased parts

Print the chassis, adapter, EDF clamp, motor clamps, roller core, bearing retainers, coupling, electronics trays, sensor cartridges/shims/clamps, contact block, service cover and grille.

Use purchased motors/electronics, silicone tires/aluminum hubs, screws and inserts, 3 mm steel roller axle, two 623 bearings (3 × 10 × 4 mm), sponge, gaskets, microfiber and thin retaining straps. Small plastic screws, a printed high-speed fan and printed roller bearings are not assumed substitutes for these parts.

M2.5 inserts are represented with 3.6 mm nominal OD. The chassis uses 3 mm long inserts where its deck is only 4 mm thick, and 4 mm inserts in raised bosses. Match the actual insert's manufacturer's hole specification before printing; nominal CAD clearance is not a universal press-fit rule. Bearing retainers use M2 screws into printed pilot holes. Thread profiles are simplified in the visual model.

## Assembly sequence

1. Print fit coupons for the chosen insert, shaft, bearing and motor-clamp interfaces. Measure actual motor bodies, shaft profile/length, hub bore and EDF casing/bore before final fit.
2. Print the chassis flat, board face on the build plate. Inspect the uninterrupted vacuum sealing face and clear the blind insert bores. Use supports for horizontal bearing pockets where needed, or drill/ream to final fit.
3. Install heat-set inserts. Assemble the four drive motors, compliant clamp pads and clamps. Engage the output shafts in the wheel hubs and secure their set screws; check free rotation and board contact.
4. Assemble the rear shaft, bearings, roller core and bearing retainers. Fit the wiper motor and coupling. Secure the core, then install the microfiber sleeve. Confirm the sleeve's compressed outside diameter and actual board contact.
5. Install the electronics trays before the modules. Use thin hook-and-loop retention straps and keep connectors clear; printed supports do not replace battery restraint.
6. Install the sensor shims, cartridges, modules and edge clamps. Set optical height and calibrate on the actual board/frame.
7. Install the flange gasket, adapter, EDF inlet gasket and purchased EDF. Verify casing OD and clamp zone against the actual duct; keep the upward exhaust unobstructed. Air enters from the board chamber through the central opening and exits upward through the axial fan.
8. Cut the sponge using the 1:1 SVG template. Confirm the 50 mm scale bar. Attach with a thin removable adhesive, accounting for its thickness in the 2 mm compressed stack. Keep the vacuum aperture and sensor windows open. The pad also follows the rear chassis extensions; its pattern is extracted directly from the model.
9. Route wiring, install the pogo contacts, and close the service cover with its four flange screws. Bond the grille bezel to the cover after its fit test. The cover has no electrical connections.

Print small clamps/trays with their broad faces on the bed. Orient the roller core vertically for its bore, and the coupling so its bore can be finished accurately. The shell may require supports at the roof and arches; orient it after checking supports in the slicer. Exported STLs preserve assembly orientation but have their lowest Z translated to zero. They are in millimeters.

## Remaining physical validation

The PDF does not identify the EDF, N20 variant, wheel SKU, PCB layouts or insert supplier. The selected EDF is the [QX-Motor 30 mm six-blade unit with QF1611](https://www.qx-motor.net/products/qx-motor-30mm-6-blades-edf-unit-with-qf1611-7000kv-14000kv-6000kv-5000kv-brushless-motor). Its product listing identifies a nominal 30 mm fan and a QF1611 motor (16.3 mm diameter × 25 mm long, 1.5 mm shaft); it does not provide a dimensioned duct ID, length or mounting drawing. The model assumes a 25.5 mm bore and 16 mm duct length from the pictured envelope, so measure the delivered unit and adjust the adapter/clamp before printing final-fit parts. The seller lists motor-only weight 19.5 g and assembled EDF weight 21.8 g; the modeled 2.3 g casing/rotor share is their difference, an estimate. This is a buildable assembly approach with provisional purchased-part interfaces, not a production-qualified design.

The nominal wheel diameter remains 22 mm from the original brief. JSumo JS2622 is a different size; do not purchase it assuming it matches. Each N20 envelope is interpreted as a 26 mm body plus 10 mm shaft. Replace those parameters with actual measured dimensions before fabricating mounts. The model selects 14,000 KV to suit 2S; the listing's 2S test point is 19.3 A, 142.82 W and 215 g thrust at full throttle, and is not a suction-pressure curve. A 500 mAh 30C pack is nominally 15 A continuous, so that setup exceeds its stated rating by 4.3 A. Limit throttle or select a battery with adequate continuous-current rating, and use suitable ESC, wiring and thermal margins.

A 56 mm circular vacuum mouth has an area of approximately 0.00246 m². At an assumed 3 kPa pressure difference, its ideal normal force would be approximately 7.39 N. This is an illustrative calculation, not a blower performance claim. The broad sponge area is not automatically effective suction area. Adhesion depends on measured pressure under leakage, wheel friction, pad drag, actual mass, compression and peeling moments.

The full pad must not lift the wheels off the board when compressed. New supports/cover/hardware add unknown mass beyond the original estimate. The model's known-mass sum is not its finished weight.

The PDF rates the N20 motors at 6 V but supplies the motor driver from 2S. Electrical power conditioning/current capability, two motors per TB6612 channel, blower compatibility and charging circuitry remain separate engineering checks.

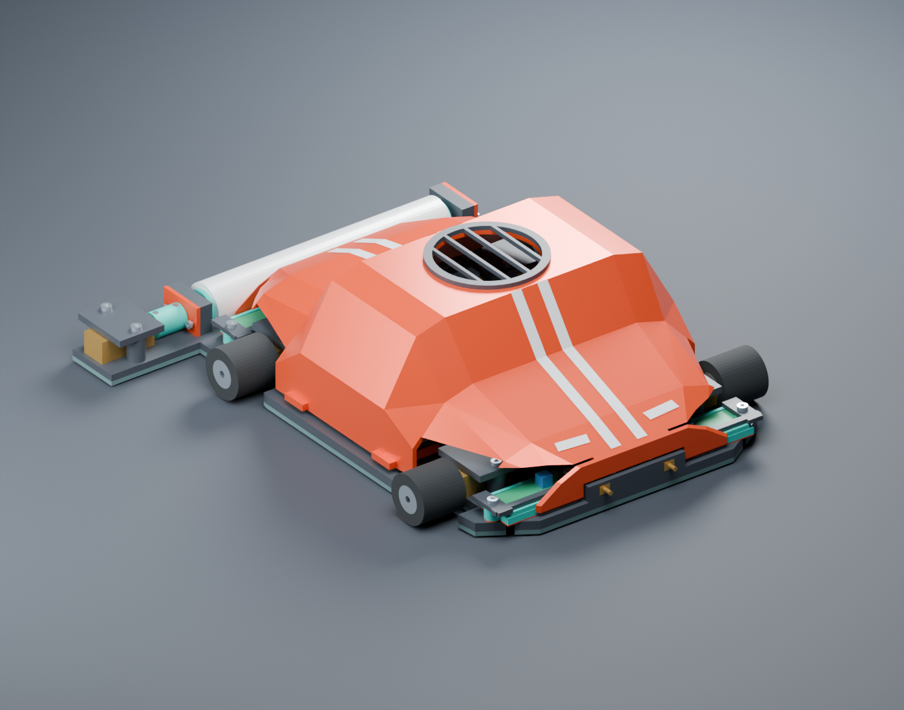
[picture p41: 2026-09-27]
robot_assembled.png

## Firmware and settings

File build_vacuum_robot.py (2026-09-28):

"""Blender 4.x/5.x blockout. Run: blender --background --python build_vacuum_robot.py
Optional script arguments after --: --output-dir DIR --godot-bin PATH --skip-godot
Destructively replaces the current scene, but never overwrites robotszivacs.blend.
Coordinates: X right, Y front, Z up. All design inputs below are millimeters.
"""
from __future__ import annotations

import argparse
import math
import os
from pathlib import Path
import shutil
import subprocess
import sys
import traceback

import bpy
import bmesh
from mathutils import Vector

MM = 0.001
VISUALS = []
COLLIDERS = []
CHASSIS = None
LOG = None
STEP = 0

ASSUMPTIONS = """- Revision 2: assembly-oriented, sports-car-style prototype; not production qualified.
- Four 6 V N20 drive motors per user decision; PDF's two-motor configuration is superseded.
- Full-footprint 2 mm sponge follows the chassis and its rear extensions, with a 56 mm
  vacuum opening, wheel reliefs and four sensor windows.
- The chassis has a 56 mm port feeding a gasketed adapter and QX-Motor 30 mm axial EDF.
  QF1611 14000 KV is modeled to match the 2S battery; confirm the motor's printed KV.
  Seller dimensions do not define duct ID/length; modeled fit envelope remains provisional.
  The vendor's 19.3 A 2S test point exceeds the modeled 500 mAh 30C pack's 15 A rating.
- Wheel envelope remains 22 x 21 mm from original request; PDF provides no exact wheel SKU.
- All nominal shaft/hub axes align. Motor envelope is interpreted as 26 mm body + 10 mm shaft.
- One unified chassis includes insert towers, rear forks and sensor support bosses.
- New cover, clamps, trays and coupling are separate printable parts, parented to Chassis.
- Use real screws, inserts, a 3 mm roller axle and 623 bearings; electronics and elastomers
  are purchased. Shaft profiles, fits and purchased hardware must be checked on a prototype.
- The original 100 g chassis allowance is retained as an estimate, not a calculated weight.
  Added hardware/printed parts and the enlarged full pad have unknown masses (-1).
- Godot collision helpers are static inspection geometry (-colonly for apertured structures).
  They are not dynamic rigid-body-ready; use convex decomposition before rigid-body use.
- Manufacturing exports are mm STL fit prototypes. Validate selected parts, pad drag,
  sealing, suction pressure/flow and wheel traction before operating on a vertical board.
"""


def log(message):
    LOG.write(message + "\n")
    LOG.flush()
    print(message, flush=True)


def bounds(obj):
    bpy.context.view_layer.update()
    points = [obj.matrix_world @ Vector(p) for p in obj.bound_box]
    low = Vector(tuple(min(p[i] for p in points) for i in range(3)))
    high = Vector(tuple(max(p[i] for p in points) for i in range(3)))
    return low, high


def triple(value):
    return "(" + ", ".join(f"{v:.4f}" for v in value) + ")"


def record(obj):
    global STEP
    STEP += 1
    low, high = bounds(obj)
    log(f"{STEP:03d}. `{obj.name}` | mesh `{obj.data.name}` | "
        f"world dimensions mm {triple((high-low)/MM)} | "
        f"world origin mm {triple(obj.matrix_world.translation/MM)} | "
        f"bounds mm {triple(low/MM)} → {triple(high/MM)} | "
        f"scale {triple(obj.scale)} | mass g {obj['Weight']} | "
        f"voltage V {obj['Voltage']} | type {obj['Part Type']}")


def material(name, color, metallic=0.0, roughness=0.6):
    mat = bpy.data.materials.new(name)
    mat.diffuse_color = (*color, 1)
    mat.use_nodes = True
    shader = mat.node_tree.nodes.get('Principled BSDF')
    shader.inputs['Base Color'].default_value = (*color, 1)
    shader.inputs['Metallic'].default_value = metallic
    shader.inputs['Roughness'].default_value = roughness
    return mat


def finish(obj, name, mass, voltage, kind, mat, collision=False, **properties):
    obj.name = name
    obj.data.name = name + '_Mesh'
    if CHASSIS is not None:
        world = obj.matrix_world.copy()
        obj.parent = CHASSIS
        obj.matrix_world = world
    obj['Weight'] = float(mass)
    obj['Voltage'] = float(voltage)
    obj['Part Type'] = kind
    obj['Weight Unit'] = 'grams; -1 = unspecified'
    obj['Voltage Unit'] = 'volts; -1 = unspecified/not applicable'
    obj['Mass Known'] = mass >= 0
    for key, value in properties.items():
        obj[key] = value
    obj.data.materials.clear()
    obj.data.materials.append(mat)
    for polygon in obj.data.polygons:
        polygon.material_index = 0
    obj['Material_Name'] = mat.name
    if collision:
        obj.display_type = 'WIRE'
        obj.hide_render = True
        obj['Physics Helper'] = True
        COLLIDERS.append(obj)
    else:
        VISUALS.append(obj)
    record(obj)
    return obj


def box(name, size, center, mass=-1, voltage=-1, kind='Component', mat=None,
        collision=False, **properties):
    bpy.ops.mesh.primitive_cube_add(size=1, location=tuple(v*MM for v in center))
    obj = bpy.context.object
    obj.dimensions = tuple(v*MM for v in size)
    bpy.ops.object.transform_apply(location=False, rotation=False, scale=True)
    return finish(obj, name, mass, voltage, kind, mat, collision, **properties)


def cylinder(name, diameter, length, center, axis='Z', mass=-1, voltage=-1,
             kind='Component', mat=None, collision=False, **properties):
    rotation = {'Z': (0, 0, 0), 'X': (0, math.pi/2, 0),
                'Y': (math.pi/2, 0, 0)}[axis]
    bpy.ops.mesh.primitive_cylinder_add(vertices=12 if collision else 32,
        radius=diameter*MM/2, depth=length*MM,
        location=tuple(v*MM for v in center), rotation=rotation)
    obj = bpy.context.object
    bpy.ops.object.transform_apply(location=False, rotation=True, scale=True)
    return finish(obj, name, mass, voltage, kind, mat, collision, **properties)


def plate_mesh(name, xs, ys, cells, bottom, top):
    """One manifold, connected grid solid, with no internal faces or boolean debris."""
    vertices, faces, indices = [], [], {}
    def vid(i, j, k):
        key = (i, j, k)
        if key not in indices:
            indices[key] = len(vertices)
            vertices.append((xs[i]*MM, ys[j]*MM, (bottom if k == 0 else top)*MM))
        return indices[key]
    for i, j in sorted(cells):
        faces.append([vid(i,j,0), vid(i,j+1,0), vid(i+1,j+1,0), vid(i+1,j,0)])
        faces.append([vid(i,j,1), vid(i+1,j,1), vid(i+1,j+1,1), vid(i,j+1,1)])
        for neighbor, edge in [((i,j-1), ((i,j),(i+1,j))),
                                ((i+1,j), ((i+1,j),(i+1,j+1))),
                                ((i,j+1), ((i+1,j+1),(i,j+1))),
                                ((i-1,j), ((i,j+1),(i,j)))]:
            if neighbor not in cells:
                a,b = edge
                faces.append([vid(*a,0), vid(*b,0), vid(*b,1), vid(*a,1)])
    mesh = bpy.data.meshes.new(name + '_Mesh')
    mesh.from_pydata(vertices, [], faces)
    mesh.update()
    obj = bpy.data.objects.new(name, mesh)
    bpy.context.collection.objects.link(obj)
    return obj


# Revision 2: assembly-oriented prototype. All design arguments are millimeters.
PRINTED = []
FASTENERS = []
MATERIALS = {}
PAD_OUTLINE = [(-52,-100),(52,-100),(68,-86),(76,-45),(76,40),(70,86),(48,100),(-48,100),(-70,86),(-76,40),(-76,-45),(-68,-86)]
WHEEL_X, WHEEL_Y, AXLE_Z = 75.0, 62.0, 11.0
PORT_D = 56.0
FIT = 0.30


def active(obj):
    bpy.ops.object.select_all(action='DESELECT')
    obj.select_set(True)
    bpy.context.view_layer.objects.active = obj


def organize_collections(scene):
    """Put the chassis assembly into visibility-toggle groups without changing parenting."""
    root = bpy.data.collections.get('Robot Components')
    if root is None:
        root = bpy.data.collections.new('Robot Components')
    if root.name not in scene.collection.children:
        scene.collection.children.link(root)
    names = (
        'Chassis', 'Vacuum System', 'Drivetrain', 'Rear Wiper',
        'Top Electronics', 'Board Sensors', 'Charging Contacts',
        'Sports Car Body', 'Other Components', 'Collision Helpers',
    )
    groups = {}
    for name in names:
        group = bpy.data.collections.get(name)
        if group is None:
            group = bpy.data.collections.new(name)
        if group.name not in root.children:
            root.children.link(group)
        groups[name] = group

    def group_for(obj):
        name = obj.name
        if obj in COLLIDERS or name.endswith(('-colonly', '-convcolonly')):
            return 'Collision Helpers'
        if name == 'Chassis': return 'Chassis'
        if name == 'Full_Bottom_Sponge' or name.startswith((
            'Vacuum_', 'EDF_', 'QF1611_')):
            return 'Vacuum System'
        if name.startswith(('Drive_', 'Wheel_', 'Motor_')):
            return 'Drivetrain'
        if name.startswith(('Wiper_', 'Roller_', 'Microfiber_', 'Bearing_')):
            return 'Rear Wiper'
        if name.startswith((
            'Battery_', 'ESP32_', 'BLHeli_', 'TB6612', 'D4184_',
            'Electronics_', 'Power_')):
            return 'Top Electronics'
        if name.startswith(('TCRT5000_', 'IR_', 'Sensor_')):
            return 'Board Sensors'
        if name.startswith(('Charging_', 'Contact_', 'Pogo_')):
            return 'Charging Contacts'
        if name.startswith((
            'Sports_Car_', 'Exhaust_', 'Racing_Stripe_', 'Headlight_')):
            return 'Sports Car Body'
        return 'Other Components'

    for obj in list(scene.objects):
        destination = groups[group_for(obj)]
        for collection in list(obj.users_collection):
            collection.objects.unlink(obj)
        destination.objects.link(obj)
        obj['Component Group'] = destination.name
    return groups


def raw_box(size, center):
    bpy.ops.mesh.primitive_cube_add(size=1, location=tuple(v*MM for v in center))
    obj = bpy.context.object
    obj.dimensions = tuple(v*MM for v in size)
    bpy.ops.object.transform_apply(location=False, rotation=False, scale=True)
    return obj


def raw_cylinder(d, length, center, axis='Z', sides=48):
    rotation = {'X':(0,math.pi/2,0),'Y':(math.pi/2,0,0),'Z':(0,0,0)}[axis]
    bpy.ops.mesh.primitive_cylinder_add(vertices=sides, radius=d*MM/2, depth=length*MM,
        location=tuple(v*MM for v in center), rotation=rotation)
    obj = bpy.context.object
    bpy.ops.object.transform_apply(location=False, rotation=True, scale=True)
    return obj


def boolean(obj, tool, operation='DIFFERENCE'):
    active(obj)
    mod = obj.modifiers.new('Mechanical interface', 'BOOLEAN')
    mod.operation = operation
    mod.solver = 'EXACT'
    mod.object = tool
    bpy.ops.object.modifier_apply(modifier=mod.name)
    bpy.data.objects.remove(tool,do_unlink=True)
    return obj


def join_solid(obj, other):
    return boolean(obj,other,'UNION')


def hole(obj, diameter, length, center, axis='Z'):
    return boolean(obj,raw_cylinder(diameter,length,center,axis))


def prism(outline, z0, z1):
    n = len(outline)
    verts = [(x*MM,y*MM,z*MM) for z in (z0,z1) for x,y in outline]
    faces = [tuple(reversed(range(n))),tuple(range(n,2*n))]
    faces += [(i,(i+1)%n,(i+1)%n+n,i+n) for i in range(n)]
    mesh=bpy.data.meshes.new('Machined profile')
    mesh.from_pydata(verts,[],faces); mesh.update()
    obj=bpy.data.objects.new('Workpiece',mesh); bpy.context.collection.objects.link(obj)
    return obj


def tube(outer, inner, length, center, axis='Z'):
    return hole(raw_cylinder(outer,length,center,axis),inner,length+2,center,axis)


def bevel(obj, width=0.5, segments=2):
    active(obj)
    mod=obj.modifiers.new('Edge relief','BEVEL'); mod.width=width*MM; mod.segments=segments
    bpy.ops.object.modifier_apply(modifier=mod.name)
    return obj


def part(obj, name, mat, kind='Printed PETG part', mass=-1, voltage=-1, printable=True, **props):
    if printable:
        props.update({'Manufacturing':'FDM prototype; fit coupon required','Fit_Clearance_mm':FIT,
                      'Print_Orientation':'See ASSEMBLY.md','Production_Validated':False})
    obj=finish(obj,name,mass,voltage,kind,mat,**props)
    if printable: PRINTED.append(obj)
    return obj


def screw(name,x,y,z,diam=2.5,length=8,axis='Z'):
    # z is the head underside for Z screws. For X, x is the head underside.
    v=Vector((x,y,z)); direction=Vector({'X':(1,0,0),'Y':(0,1,0),'Z':(0,0,1)}[axis])
    obj=raw_cylinder(diam,length,v-direction*length/2,axis,24)
    if 'SetScrew' not in name:
        join_solid(obj,raw_cylinder(diam*1.8,diam*.65,v+direction*(diam*.325-.02),axis,24))
    hole(obj,diam*.75,diam*.5,v+direction*diam*.6,axis)
    out=part(obj,name,MATERIALS['metal'],'Purchased socket screw',-1,printable=False,
             Thread=f'M{diam}',Length_mm=length,Thread_Geometry='Simplified smooth shank')
    FASTENERS.append(out)
    return out


def insert(name,x,y,z,diam=3.6,length=4):
    obj=tube(diam,2.1,length,(x,y,z))
    return part(obj,name,MATERIALS['brass'],'Purchased M2.5 heat-set insert',-1,
                printable=False,Nominal_OD_mm=diam,Fit_Status='Match purchased insert and coupon')


def recesses(obj, pad=False):
    for x in (-WHEEL_X,WHEEL_X):
        for y in (-WHEEL_Y,WHEEL_Y):
            boolean(obj,raw_box((28,29,12),(x,y,3)))
    hole(obj,PORT_D,20,(0,0,3))
    for x in (-43,43):
        for y in (-87,87):
            boolean(obj,raw_box((33,15,14),(x,y,3)))
    return obj


def loft(stations, bottom=8, inset=0):
    vertices=[]
    for y,w,h in stations:
        w-=inset; h-=inset
        profile=[(-w,bottom),(-w,h*.50),(-w*.78,h-4),(-w*.58,h),
                 (w*.58,h),(w*.78,h-4),(w,h*.50),(w,bottom)]
        vertices.extend((x*MM,y*MM,z*MM) for x,z in profile)
    faces=[tuple(reversed(range(8))),tuple(range((len(stations)-1)*8,len(stations)*8))]
    for j in range(len(stations)-1):
        for i in range(8): faces.append((j*8+i,j*8+(i+1)%8,(j+1)*8+(i+1)%8,(j+1)*8+i))
    mesh=bpy.data.meshes.new('Coachwork loft'); mesh.from_pydata(vertices,[],faces); mesh.update()
    obj=bpy.data.objects.new('Coachwork',mesh); bpy.context.collection.objects.link(obj)
    # Recalculate to ensure boolean operands have consistently outward normals.
    bm=bmesh.new(); bm.from_mesh(mesh); bmesh.ops.recalc_face_normals(bm,faces=list(bm.faces)); bmesh.ops.triangulate(bm,faces=list(bm.faces)); bm.to_mesh(mesh); bm.free()
    return obj


def construct():
    global CHASSIS
    PRINTED.clear(); FASTENERS.clear()
    colors={'body':((0.88,.075,.018),.28,.3),'base':((.055,.07,.09),.15,.5),
      'rubber':((.018,.024,.028),0,.9),'sponge':((.10,.20,.21),0,1),
      'metal':((.52,.61,.69),.8,.28),'brass':((.62,.38,.10),.65,.35),
      'teal':((.02,.62,.53),.1,.55),'battery':((.12,.17,.23),.1,.5),
      'pcb':((.025,.33,.16),0,.5),'blue':((.035,.22,.55),.1,.4),
      'white':((.88,.94,.98),.15,.3),'red':((.58,.006,.01),.2,.3),
      'proxy':((1,.05,.6),0,.8)}
    MATERIALS.clear()
    for name,(color,metal,rough) in colors.items(): MATERIALS[name]=material(name,color,metal,rough)
    M=MATERIALS
    # One continuous chassis with all permanent bosses, roller arms and motor support.
    chassis=recesses(prism(PAD_OUTLINE,2,6))
    # Wheel motor clamps attach to blind insert towers, keeping the board face sealed.
    for s in (-1,1):
        for y in (-62,62):
            for dy in (-10,10):
                join_solid(chassis,raw_cylinder(8,10.5,(s*49,y+dy,11.15),sides=24))
                hole(chassis,3.7,4.3,(s*49,y+dy,14.35))
    # Electronics trays use captive chassis insert seats.
    for x,y in [(-31,-57),(31,-57),(-30,58),(30,58),(-60,-12),(58,-18),(58,21)]:
        join_solid(chassis,raw_cylinder(8,3.2,(x,y,7.4),sides=24))
        hole(chassis,3.7,4.2,(x,y,6.9))
    # Blower adapter M2.5 blind insert seats, around a real 56 mm through-port.
    for x in (-25,25):
        for y in (-25,25): hole(chassis,3.7,3.2,(x,y,4.5))
    # Removable cover: four low flanges, outside electronic and fan clearance.
    for x in (-66,66):
        for y in (-29,29):
            join_solid(chassis,raw_cylinder(9,2.4,(x,y,7),sides=24))
            hole(chassis,3.7,4.2,(x,y,6.1))
    # Integral rear fork; right extension carries the fifth motor.
    for x in (-65,65):
        join_solid(chassis,raw_box((12,34,3),(x,-103,3.5)))
        block=raw_box((6,22,16),(x,-111,10))
        hole(block,3.4,10,(x,-111,10),'X')
        # Outward-facing bearing pocket and an inner retention shoulder.
        hole(block,10.2,4.4,(x+math.copysign(1,x),-111,10),'X')
        for yy in (-119,-103): hole(block,1.7,9,(x,yy,10),'X')
        join_solid(chassis,block)
    join_solid(chassis,raw_box((56,26,3),(87,-109,3.5)))
    for y in (-121,-101):
        join_solid(chassis,raw_cylinder(8,10.5,(99,y,10.15),sides=24))
        hole(chassis,3.7,4.3,(99,y,13.35))
    # Sensor retainers are supported by integral ledges and blind screw bosses.
    for x in (-43,43):
        for y in (-87,87):
            for dx in (-19,19):
                join_solid(chassis,raw_cylinder(7,4,(x+dx,y,4),sides=24))
                hole(chassis,3.7,3.2,(x+dx,y,4.5))
    CHASSIS=part(chassis,'Chassis',M['base'],mass=100,
       Weight_Basis='Original 100 g chassis allowance; enlarged prototype must be weighed',
       Ground_Clearance_mm=2,Vacuum_Port_Diameter_mm=56)
    # Derive the pad directly from the complete chassis contact footprint, including forks.
    pad=bpy.data.objects.new('Pad footprint workpiece',CHASSIS.data.copy())
    bpy.context.collection.objects.link(pad)
    boolean(pad,raw_box((400,400,.7),(0,0,2.15)),'INTERSECT')
    for vertex in pad.data.vertices:
        vertex.co.z=(vertex.co.z-2*MM)*4
    pad.data.update()
    part(pad,'Full_Bottom_Sponge',M['sponge'],'Die-cut closed-cell sponge pad',-1,
         printable=False,Compressed_Thickness_mm=2,Attachment='Thin removable adhesive; include in 2 mm stack',
         Coverage='Entire chassis contact footprint including rear extensions, with functional openings')
    gasket=tube(80,56,.5,(0,0,6.25))
    for x in (-25,25):
        for y in (-25,25): hole(gasket,2.8,3,(x,y,6.25))
    part(gasket,'Vacuum_Flange_Gasket',M['rubber'],'Cut silicone gasket',-1,printable=False)
    # Hollow tapered adapter: 56 mm mouth to a provisional 26.5 mm EDF bore.
    bpy.ops.mesh.primitive_cone_add(vertices=64,radius1=30*MM,radius2=15.8*MM,
                                    depth=10*MM,location=(0,0,11.5*MM))
    adapter=bpy.context.object
    join_solid(adapter,raw_cylinder(80,3,(0,0,8)))
    bpy.ops.mesh.primitive_cone_add(vertices=64,radius1=29.3*MM,radius2=13.25*MM,
                                    depth=12*MM,location=(0,0,11.5*MM))
    boolean(adapter,bpy.context.object)
    for x in (-25,25):
        for y in (-25,25): hole(adapter,2.8,8,(x,y,8))
    # Three screws hold the EDF casing clamp; towers overlap the taper's outer wall.
    for a in (30,150,270):
        x,y=24*math.cos(math.radians(a)),24*math.sin(math.radians(a))
        join_solid(adapter,raw_cylinder(8,9,(x,y,12),sides=24))
        hole(adapter,2.1,7,(x,y,14))
    part(adapter,'Vacuum_Adapter',M['teal'],Inlet_mm=56,Outlet_mm=26.5,
         Fit_Status='Provisional throat matches estimated EDF clear bore; confirm purchased duct ID')
    for x in (-25,25):
        for y in (-25,25):
            insert(f'Vacuum_Insert_{x}_{y}',x,y,4.5,length=3)
            screw(f'Vacuum_Flange_Screw_{x}_{y}',x,y,9.5,length=6)
    part(tube(32,26.5,.5,(0,0,16.25)),'EDF_Inlet_Gasket',M['rubber'],
         'Cut silicone EDF inlet gasket',-1,printable=False,
         Fit_Status='26.5 mm opening is provisional; measure EDF bore and inlet lip')

    # QX-Motor 30 mm six-blade EDF; nominal duct OD 30, motor Ø16.3 x 25.
    # Vendor does not publish duct ID/length drawing: 25.5 mm ID x 16 mm is a fit envelope.
    edf=raw_cylinder(30,16,(0,0,24.5),'Z',72)
    boolean(edf,raw_cylinder(25.5,18,(0,0,24.5),'Z',72))
    # Three short stator spokes support the motor inside the annular airflow path.
    for angle in (90,210,330):
        phi=math.radians(angle)
        r=(7.4+13.0)/2
        outline=[]
        for rr,side in [(7.4,-.65),(13.0,-.65),(13.0,.65),(7.4,.65)]:
            outline.append((rr*math.cos(phi)-side*math.sin(phi),
                            rr*math.sin(phi)+side*math.cos(phi)))
        join_solid(edf,prism(outline,25.6,27.2))
    part(edf,'EDF_30mm_Duct_Stators',M['base'],'Purchased polycarbonate EDF casing',2.3,7.4,False,
         Manufacturer='QX-Motor 30 mm 6-blade EDF with QF1611',
         Nominal_Outer_Diameter_mm=30,Manufacturer_Duct_ID_mm=-1,
         Modeled_Bore_mm=25.5,Manufacturer_Duct_Length_mm=-1,Modeled_Length_mm=16,
         Fit_Status='OD follows 30 mm product name; ID/length measured from image only, verify part')

    # Six slim, separate vane profiles join a central hub; this is an envelope, not rotor CAD.
    impeller=raw_cylinder(11,.8,(0,0,18.15),'Z',48)
    for index in range(6):
        base_angle=math.radians(index*60)
        stations=[(5.3,-10),(8.0,-14),(11.8,-9),(12.25,-3),
                  (12.25,4),(8.0,0),(5.3,7)]
        polygon=[(r*math.cos(base_angle+math.radians(a)),
                  r*math.sin(base_angle+math.radians(a))) for r,a in stations]
        join_solid(impeller,prism(polygon,17.8,18.5))
    part(impeller,'EDF_Six_Blade_Impeller',M['metal'],'Six-blade EDF rotor envelope',-1,7.4,False,
         Blade_Count=6,Rotation_Axis='Z',Rotation_Speed_RPM=-1,
         Fit_Status='Visual vane blockout; not an aerodynamic or balanced rotor model')
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

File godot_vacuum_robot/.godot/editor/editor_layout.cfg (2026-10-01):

[docks]

dock_3="Scene,Import"
dock_3_selected_tab_idx=0
dock_4="FileSystem,History"
dock_4_selected_tab_idx=0
dock_5="Inspector,Signals,Groups"
dock_5_selected_tab_idx=0
dock_9="Output,Debugger,Audio,Animation,Shader Editor,Search Results,AnimationTree,MeshLibrary,ResourcePreloader,ShaderFile,SpriteFrames,Theme,Polygon,TileSet,TileMap,Replication,GridMap"
dock_floating={}
dock_closed=[]
dock_split_2=0
dock_split_3=0
dock_hsplit_1=0
dock_hsplit_2=280
dock_hsplit_3=-280
dock_hsplit_4=0
dock_main_split=0
dock_bottom_split=0
dock_9_selected_tab_idx=0

[docks/FileSystem]

h_split_offset=480
v_split_offset=0
display_mode=0
file_sort=0
file_list_display_mode=1
selected_paths=PackedStringArray("res://Vacuum_Robot_Blockout.glb")
uncollapsed_paths=PackedStringArray("res://")

[docks/History]

include_scene=true
include_global=true

[docks/Theme]

split_offset=520

[EditorNode]

open_scenes=PackedStringArray("res://node_3d.tscn", "res://main.tscn")
current_scene="res://node_3d.tscn"
bottom_panel_offsets={
"Audio": -450.0,
"Output": -270.0
}
selected_default_debugger_tab_idx=0
selected_main_editor_idx=1

[EditorWindow]

screen=0
mode="maximized"
position=Vector2i(0, 75)

[ScriptEditor]

open_scripts=["res://main.gd", "res://player.gd"]
selected_script="res://main.gd"
open_help=[]
script_split_offset=400
list_split_offset=0
zoom_factor=1.0

[GameView]

floating_window_rect=Rect2i(6326, 1368, 1856, 1492)
floating_window_screen=0

[ShaderEditor]

open_shaders=[]
split_offset=400
selected_shader=""
text_shader_zoom_factor=1.0

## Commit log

2026-09-28 mod(godot): made the game look kind of real
    [editor_layout.cfg]
2026-10-01 mate prezije
    [editor_layout.cfg, project_metadata.cfg]
